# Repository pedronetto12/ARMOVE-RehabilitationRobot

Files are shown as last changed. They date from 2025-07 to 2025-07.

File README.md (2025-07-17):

# ARMOVE - Omnidirectional Robotic Device for Upper Limb Rehabilitation



**Author:** Pedro Netto Gandolfi Grangeiro 
**Advisor:** Prof. Dr. Fabricio Noveletto 
**Institution:** Universidade do Estado de Santa Catarina (UDESC) 
**Course:** Bachelor's in Electrical Engineering 

This repository contains all the necessary files and documentation for the ARMOVE project, an active omnidirectional robotic device for the gross motor function rehabilitation of the upper limb. The project was developed as a Final Coursework (TCC) for the Bachelor's degree in Electrical Engineering at UDESC, Joinville.

---

## 📖 Overview

Motivated by the significant impact of Stroke (CVA) and the high cost of conventional robotic therapies, this project aimed to develop a low-cost, open-source, omnidirectional prototype for the active rehabilitation of the upper limb. 
The device, functionally inspired by the commercial Armotion system, allows a patient to control its movement by applying force to a handle.  It uses a set of Mecanum wheels for omnidirectional mobility and a force-sensing system to interpret the user's intent.  The processed data is then used to move the robot and can be simultaneously transmitted via Bluetooth to a computer, emulating a mouse for interaction with therapeutic games (gamification).

This work delivers a validated, open-source platform, demonstrating the feasibility of more accessible assistive technologies and inviting multidisciplinary collaboration for its evolution into a complete clinical tool.

<div align="center">
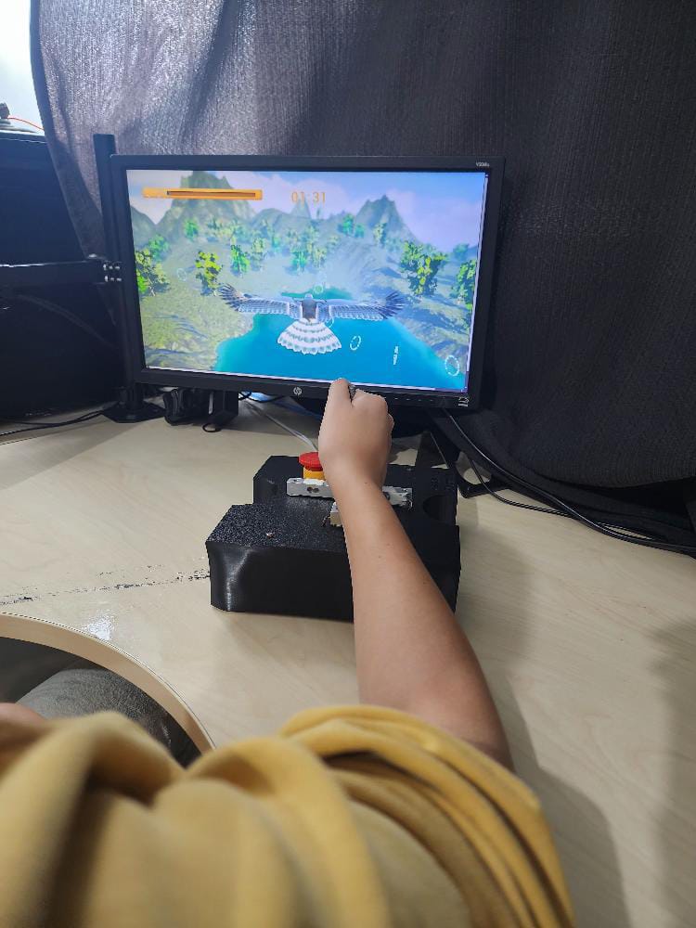
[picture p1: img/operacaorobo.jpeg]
ARMOVE em operação
  
</div>

## ✨ Features

* **Omnidirectional Movement:** Utilizes four Mecanum wheels driven by NEMA 17 stepper motors, allowing for fluid, planar movement in any direction (X-Y plane) without needing to reorient the chassis. 
* **Force-Based Active Control:** The robot operates in an active mode, where the speed and direction of movement are proportional to the force applied by the user on a central joystick. 
* **Smooth Motion Profile:** Implements a non-linear, sigmoidal control law using a hyperbolic tangent (`tanh`) function to ensure smooth acceleration and deceleration, enhancing patient safety and comfort. 
* **Real-Time Processing:** Built on an ESP32 microcontroller running the FreeRTOS real-time operating system, guaranteeing responsive and deterministic control. 
* **Wireless Connectivity:** Features Bluetooth Low Energy (BLE) to connect to external devices, emulating a Human Interface Device (HID) mouse for immediate visual feedback and interaction with rehabilitation software. 
* **Open Source:** All design files, including firmware source code, 3D models for the chassis, and electronic diagrams, are publicly available to encourage collaboration and further development.

## 🛠️ Hardware

The prototype integrates the following key components:

| Component | Model/Type | Function |
| :--- | :--- | :--- |
| **Microcontroller** | ESP32-WROOM-32 | Central processing unit, managing sensors, motors, and BLE communication.  |
| **Actuators** | 4x NEMA 17 Stepper Motors | Provide high-torque, precise movement for the wheels.  |
| **Motor Drivers** | 4x A4988 | Control the current and stepping of the NEMA 17 motors.  |
| **Wheels** | 4x 60mm Mecanum Wheels | Enable omnidirectional movement. |
| **Force Sensors** | 4x Micro Load Cells (CZL635) | Measure the force applied by the user in the X and Y axes. |
| **Sensor Amplifiers** | 4x HX711 ADC Modules | Amplify and convert the analog signal from the load cells to a 24-bit digital value. |
| **Power System** | 5S Li-ion Battery Pack (21V) with BMS | Powers the entire system safely. |
| **Voltage Regulator** | LM2596 DC-DC Buck Converter | Steps down the battery voltage for the microcontroller and logic circuits. |
| **Chassis** | Custom 3D Printed (PLA) | Houses all electronic and mechanical components. |

### Electrical Diagram
The complete electrical schematic detailing the interconnections between all components can be found at the link.
[Electrical Diagram](https://github.com/pedronetto12/ARMOVE-RehabilitationRobot/blob/main/img/Schematic_tccpedronetto_2025-07-16.png)

## 💻 Software

The embedded software is built using the **PlatformIO** framework within VSCode. This ensures a reproducible build environment by managing exact versions of libraries and the ESP32 hardware platform (`espressif32@6.2.0`). 

### Architecture
The architecture is modular and built upon the **FreeRTOS** real-time operating system to handle concurrent tasks efficiently. 
* **Key Modules:**
    * `celulas.h`: Manages data acquisition and processing from the HX711 load cells.
    * `motor.h`: Handles the control logic, kinematics, and pulse generation for the stepper motors.
    * `robomouse.h`: Manages the BLE connection and HID mouse emulation.
* **Real-Time Tasks:**
    1.  **Motor Control (`ContrMotores`):** A high-priority task running every 2 ms to ensure fluid motor updates.
    2.  **Sensor Reading (`atuador`):** A task dedicated to reading and processing data from the load cells.
    3.  **Bluetooth (`ContrMouse`):** A lower-priority task that sends cursor movement data over BLE.
    4.  **LED Status (`ledTask`):** A simple task to provide visual feedback on the system's state.

## ⚙️ Installation & Setup

1.  **Clone the Repository:**
    ```bash
    git clone [https://github.com/pedronetto12/ARMOVE-Rehabilitation-Robot.git](https://github.com/pedronetto12/ARMOVE-Rehabilitation-Robot.git)
    cd ARMOVE-Rehabilitation-Robot
    ```
2.  **Hardware Assembly:** Assemble the mechanical and electronic components according to the electrical diagram and 3D models. The 3D models (`.stl` files) for printing are available in the `/3d_models` directory.
3.  **Software Environment:**
    * Install [Visual Studio Code](https://code.visualstudio.com/).
    * Install the [PlatformIO IDE extension](https://platformio.org/platformio-ide) from the VSCode marketplace.
4.  **Build and Upload:**
    * Open the cloned repository folder in VSCode.
    * PlatformIO will automatically detect the `platformio.ini` file and prompt you to install the required libraries and toolchains.
    * Connect the ESP32 to your computer.
    * Build and upload the firmware using the PlatformIO toolbar (click the "Upload" arrow icon).

## 🎛️ Calibration

Before operation, two critical calibration procedures must be performed to ensure accuracy and safety.

### 1. A4988 Stepper Driver Calibration
This procedure sets the maximum current for the stepper motors to prevent overheating.

1.  **Calculate V_REF:** The target current was set to **1.0A** (80% of the motor's 1.3A rating).  With 0.1Ω sense resistors on the A4988 modules, the target reference voltage (V_REF) is **0.8V (800mV)**. 
2.  **Adjust Potentiometer:**
    * Power the logic and motor circuits. **Do not connect the motors yet.** 
    * Using a multimeter, measure the voltage between the `GND` pin and the metal top of the potentiometer on one of the A4988 drivers.
    * Slowly turn the potentiometer with a small screwdriver until the multimeter reads **0.800V**. 
    * Repeat this process for all four drivers.

### 2. Load Cell (HX711) Calibration
This procedure determines the calibration factor needed to convert the raw ADC readings into grams.

1.  **Load Calibration Sketch:** Use a standard HX711 calibration sketch (like the one found in the `HX711_ADC` library examples).
2.  **Run the Procedure:**
    * Upload and run the sketch on the ESP32 with the load cells connected.
    * Open the Serial Monitor. Follow the on-screen instructions.
    * First, the program will perform a tare (zeroing) with no weight on the platform.
    * Next, place a **known weight** (e.g., 5 kg) on the sensor platform.
    * Enter the known weight value (e.g., `5000.0` for grams) into the serial monitor.
    * The sketch will calculate and display a new calibration factor.
3.  **Update Firmware:** Record the calibration factors for each of the four load cells and update the following `#define` constants in `/include/celulas.h`:
    ```cpp
    #define calValueCellXp 43.53 // Replace with your value
    #define calValueCellXn 41.06 // Replace with your value
    #define calValueCellYp 43.22 // Replace with your value
    #define calValueCellYn 43.50 // Replace with your value
    ```

## ▶️ How to Operate

1.  **Power On:** Turn on the main power switch. The onboard LED will blink during initialization.
2.  **Ready State:** The LED will turn solid, indicating that initialization is complete and the device is ready. The BLE service is now advertising.
3.  **Connect via Bluetooth:** On a computer, search for Bluetooth devices and pair with **"Rehabilitation Robot"**. The device will be recognized as a standard mouse.
4.  **Begin Therapy:**
    * Place the robot on a flat, smooth surface.
    * The user places their hand on the joystick/handle and applies force in the desired direction of movement.
    * The robot will move across the surface, and the computer's cursor will move in sync, allowing interaction with games or other rehabilitation software.

## 🚧 Limitations & Future Work

While the prototype successfully validates the core concept, several limitations were identified that pave the way for future improvements.

### Current Limitations
* **Active Mode Only:** The current design is only suitable for patients who can actively generate force. It does not support passive (robot-led) or active-assistive modes for patients with more severe impairment.
* **Rotational Drift:** The device experiences minor, unintentional rotations around its central axis during movement, which can accumulate over time.
* **Sensor Drift:** The load cells can exhibit drift and hysteresis, especially under traction forces, preventing a perfect return to zero.

### Future Development Roadmap
The evolution of this project depends on a multidisciplinary effort. Key areas for future work include:

1.  **Hardware Enhancements:**
    * **Orientation Control:** Integrate an Inertial Measurement Unit (IMU) (e.g., MPU6050) to implement a closed-loop control system that corrects rotational drift.
    * **Passive/Assistive Modes:** Add encoders to the motors for position feedback, enabling the implementation of passive and active-assistive therapeutic modes.
    * **Sensor Redesign:** Explore bidirectional force sensors or a new mechanical arrangement to eliminate sensor drift.
2.  **Software Development:**
    * **Gamification Suite:** Develop a dedicated suite of therapeutic games that leverage the device's IHM for engaging and measurable rehabilitation exercises.
3.  **Clinical Validation:**
    * Collaborate with physiotherapists and occupational therapists to conduct usability tests and controlled clinical trials to validate the device's therapeutic effectiveness.

## 🤝 How to Contribute

This is an open-source project, and contributions are highly welcome! To contribute:

1.  Fork the repository.
2.  Create a new branch (`git checkout -b feature/YourFeature`).
3.  Commit your changes (`git commit -m 'Add some feature'`).
4.  Push to the branch (`git push origin feature/YourFeature`).
5.  Open a Pull Request.

Please open an issue to discuss any major changes you would like to make.

## 📜 License

This project is licensed under the MIT License. See the [LICENSE](LICENSE.md) file for details.

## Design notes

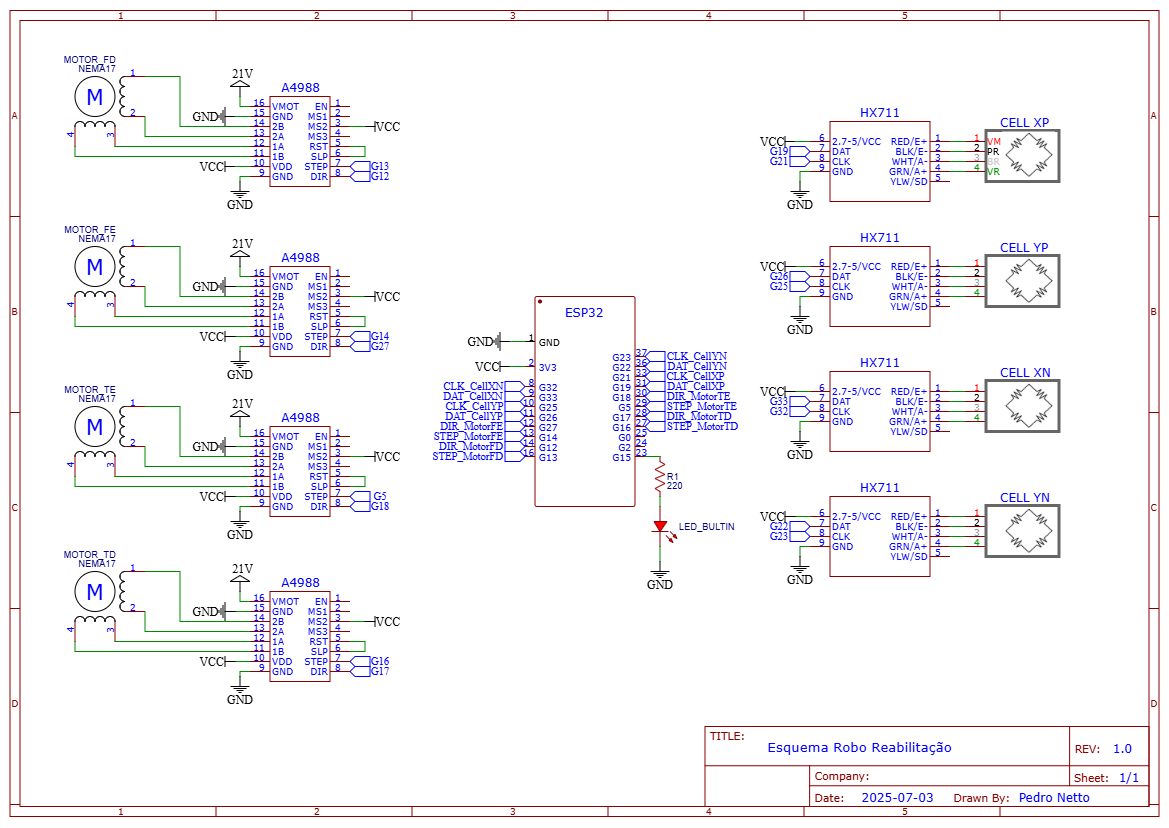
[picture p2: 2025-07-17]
img/Schematic_tccpedronetto_2025-07-16.png

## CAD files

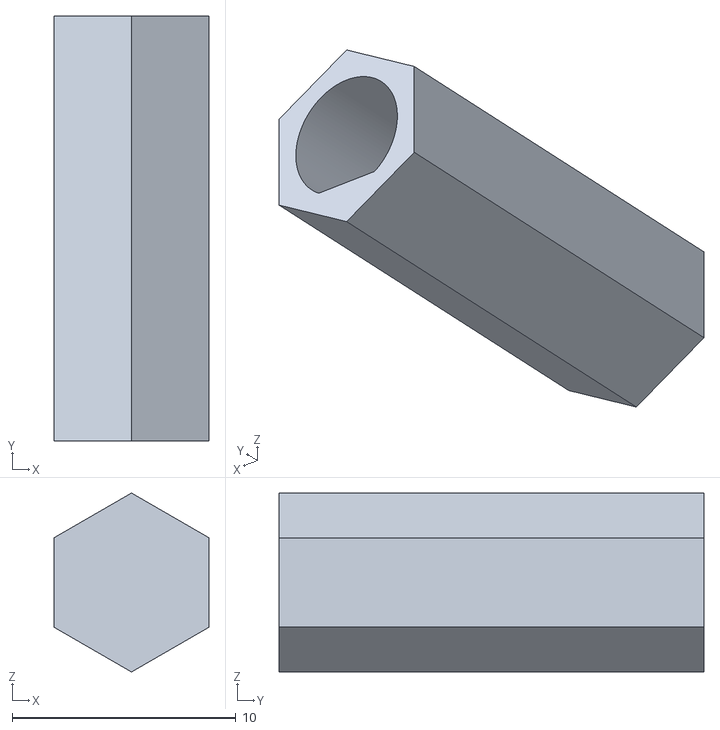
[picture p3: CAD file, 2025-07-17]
SLT_FILES/luva direta.stl
6.93 x 19.0 x 8.00

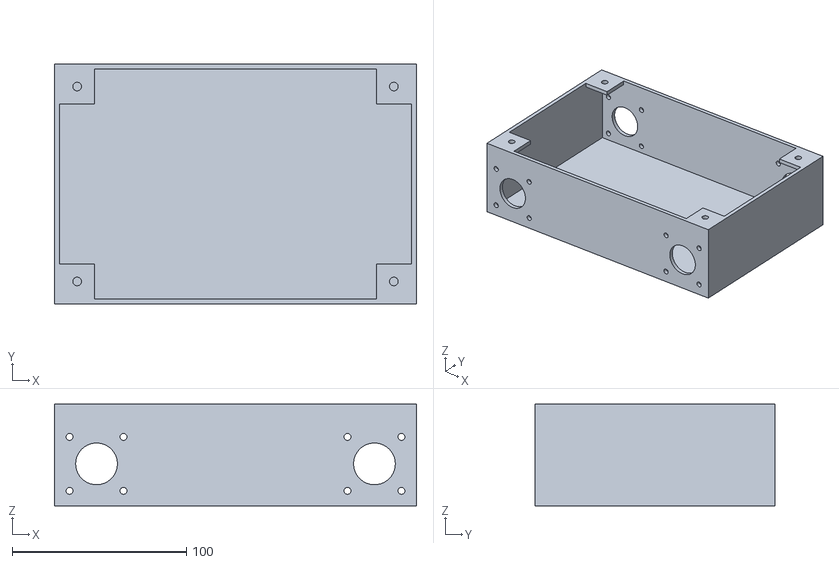
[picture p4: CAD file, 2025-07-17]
SLT_FILES/base case tcc pedro.stl
208.0 x 138.0 x 58.5

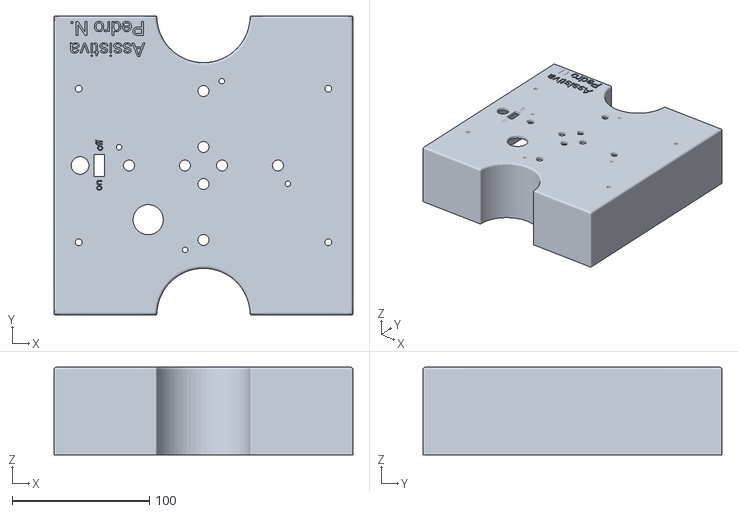
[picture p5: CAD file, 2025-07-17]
SLT_FILES/topo tcc pedro222.stl
218.0 x 218.0 x 64.0

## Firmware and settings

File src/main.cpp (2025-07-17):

#include <main.h>

void setup() {
  WRITE_PERI_REG(RTC_CNTL_BROWN_OUT_REG, 0);// desliga o brownout detector, se nao o modulo fica resetando
  Serial.begin(115200);

  xTaskCreatePinnedToCore(ledTask, "LED", 1024, NULL, 1, NULL, 1);
  CellInit(); //inicializa e configura a leitura das celulas de carga
  MotorInit(); //inicializa as configs dos motores
  MouseInit(); //inicializa as configs do Mouse

  xTaskCreatePinnedToCore(atuador,"celula_carga",1024 * 2, NULL, 1, NULL, 1);
  xTaskCreatePinnedToCore(ContrMotores,"Ctrlmotores",1024 * 2, NULL, 2, NULL, 1);
  xTaskCreatePinnedToCore(ContrMouse,"Contrmouse",1024 * 2, NULL, 3, NULL, 1);
  Inicializado = true;
}

void loop() {}

void ContrMotores (void *parameters){
  const TickType_t xDelay = pdMS_TO_TICKS(1);  // 2ms -> ticks
  while(1){
    motorRun();
    vTaskDelay(xDelay);  // Espera 2ms antes de rodar de novo
  }
}

void atuador (void *parameters){
  const TickType_t yDelay = pdMS_TO_TICKS(1);  // 2ms -> ticks
  while(1){
    leituraCelulas();
    vTaskDelay(yDelay);  // Espera 2ms antes de rodar de novo
  }
}

void ContrMouse (void *parameters){
  const TickType_t zDelay = pdMS_TO_TICKS(20);  // 20ms -> ticks
  while(1){
    MoveCursor(getLoadCellValues());
    vTaskDelay(zDelay);  // Espera 20ms antes de rodar de novo
  }
}


void ledTask(void *parameters) {
  const TickType_t delayTime = pdMS_TO_TICKS(300); // 300ms
  pinMode(LED_BUILTIN, OUTPUT);
  while (1) {
    if(Inicializado){
      digitalWrite(LED_BUILTIN, HIGH);
    }else{
      digitalWrite(LED_BUILTIN, HIGH);
      vTaskDelay(delayTime);
      digitalWrite(LED_BUILTIN, LOW);
      vTaskDelay(delayTime);
    }
  }
}

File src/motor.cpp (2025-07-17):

#include <motor.h>

  esp_timer_handle_t periodic_timer;
  //motores
  MOTOR Motor_FE={0,0,0,0,0};
  MOTOR Motor_TE={0,0,0,0,0};
  MOTOR Motor_FD={0,0,0,0,0};
  MOTOR Motor_TD={0,0,0,0,0};

void MotorInit(){
  Serial.println("Inicio do Init Motores");
  //timer interrupção
  const esp_timer_create_args_t periodic_timer_args = {
    .callback = &onTimer,
    .arg = nullptr,
    .dispatch_method = ESP_TIMER_TASK,
    .name = "motor_step_timer"
  };

  esp_timer_create(&periodic_timer_args, &periodic_timer);
  esp_timer_start_periodic(periodic_timer, 50); // 50us

  pinMode(motorFE_STEP_PIN, OUTPUT);
  pinMode(motorFE_DIR_PIN, OUTPUT);

  pinMode(motorTE_STEP_PIN, OUTPUT);
  pinMode(motorTE_DIR_PIN, OUTPUT);

  pinMode(motorFD_STEP_PIN, OUTPUT);
  pinMode(motorFD_DIR_PIN, OUTPUT);

  pinMode(motorTD_STEP_PIN, OUTPUT);
  pinMode(motorTD_DIR_PIN, OUTPUT);

  delay(200);
  Serial.println("Fim do Init Motores");
}

void moveByLoadCells(LoadCellData CellData) {
  // Ajuste das velocidades com interpolação linear
  int speedForward = linearInterpolate(CellData.forward, CellDeadZone, CellMax, minWheelSpeed, maxWheelSpeed);
  int speedSideways = linearInterpolate(CellData.sideways, CellDeadZone, CellMax, minWheelSpeed, maxWheelSpeed);
   
  // Cálculo da decomposição de velocidade dos motores
  Motor_FE.Interpolacao = speedForward + speedSideways;  
  Motor_TE.Interpolacao = speedForward - speedSideways;
  Motor_FD.Interpolacao = speedForward - speedSideways;
  Motor_TD.Interpolacao = speedForward + speedSideways;

  // Normalização para evitar saturação
  int maxSpeed = max(abs(Motor_FE.Interpolacao), max(abs(Motor_TE.Interpolacao), max(abs(Motor_FD.Interpolacao), abs(Motor_TD.Interpolacao))));
  if (maxSpeed > maxWheelSpeed) {
    float scale = (float)maxWheelSpeed / maxSpeed;
    Motor_FE.Interpolacao *= scale;
    Motor_TE.Interpolacao *= scale;
    Motor_FD.Interpolacao *= scale;
    Motor_TD.Interpolacao *= scale;
 }
}


void SuavizacaoVelocidade(){
  // Calculo do Pulso do motor frente esquerda
  if(Motor_FE.Interpolacao > 0) Motor_FE.Velocidade = (minVel-maxVel)* tanh(k * pow(abs(Motor_FE.Interpolacao), pot));
  else  Motor_FE.Velocidade = -(minVel-maxVel)* tanh(k * pow(abs(Motor_FE.Interpolacao), pot));

  if(Motor_FE.Interpolacao > 0) Motor_FE.Velocidade = minVel - Motor_FE.Interpolacao;
  else if(Motor_FE.Interpolacao < 0) Motor_FE.Velocidade = -minVel - Motor_FE.Interpolacao;
  else Motor_FE.Velocidade = 0;

  // Calculo do Pulso do motor traseira esquerda
  if(Motor_TE.Interpolacao > 0) Motor_TE.Velocidade = (minVel-maxVel)* tanh(k * pow(abs(Motor_TE.Interpolacao), pot));
  else  Motor_TE.Velocidade = -(minVel-maxVel)* tanh(k * pow(abs(Motor_TE.Interpolacao), pot));

  if(Motor_TE.Interpolacao > 0) Motor_TE.Velocidade = minVel - Motor_TE.Interpolacao;
  else if(Motor_TE.Interpolacao < 0) Motor_TE.Velocidade = -minVel - Motor_TE.Interpolacao;
  else Motor_TE.Velocidade = 0;

  // Calculo do Pulso do motor frente direita
  if(Motor_FD.Interpolacao > 0) Motor_FD.Velocidade = (minVel-maxVel)* tanh(k * pow(abs(Motor_FD.Interpolacao), pot));
  else  Motor_FD.Velocidade = -(minVel-maxVel)* tanh(k * pow(abs(Motor_FD.Interpolacao), pot));

  if(Motor_FD.Interpolacao > 0) Motor_FD.Velocidade = minVel - Motor_FD.Interpolacao;
  else if(Motor_FD.Interpolacao < 0) Motor_FD.Velocidade = -minVel - Motor_FD.Interpolacao;
  else Motor_FD.Velocidade = 0;

  // Calculo do Pulso do motor traseira direita
  if(Motor_TD.Interpolacao > 0) Motor_TD.Velocidade = (minVel-maxVel)* tanh(k * pow(abs(Motor_TD.Interpolacao), pot));
  else  Motor_TD.Velocidade = -(minVel-maxVel)* tanh(k * pow(abs(Motor_TD.Interpolacao), pot));

  if(Motor_TD.Interpolacao > 0) Motor_TD.Velocidade = minVel - Motor_TD.Interpolacao;
  else if(Motor_TD.Interpolacao < 0) Motor_TD.Velocidade = -minVel - Motor_TD.Interpolacao;
  else Motor_TD.Velocidade = 0;

  Motor_FE.pulseOUTPUT = Motor_FE.Velocidade;
  Motor_TE.pulseOUTPUT = Motor_TE.Velocidade;
  Motor_FD.pulseOUTPUT = -Motor_FD.Velocidade; //negativo pois foram colocados do lado espelhado do esquerdo
  Motor_TD.pulseOUTPUT = -Motor_TD.Velocidade; //negativo pois foram colocados do lado espelhado do esquerdo

  /*
  Motor_FE.pulseOUTPUT = 120;
  Motor_TE.pulseOUTPUT = 120;
  Motor_FD.pulseOUTPUT = -120;
  Motor_TD.pulseOUTPUT = -120;
  */
}

void motorRun(){
  moveByLoadCells(getLoadCellValues());
  SuavizacaoVelocidade();
  //printdebug(getLoadCellValues());
}


void printdebug(LoadCellData CellData){
  Serial.print(Motor_FE.Interpolacao);
  Serial.print(",,");
  Serial.print(CellData.pesoYp);
  Serial.print("    ");

  Serial.print(Motor_TE.Interpolacao);
  Serial.print(",,");
  Serial.print(CellData.pesoYn);
  Serial.print("    ");

  Serial.print(Motor_FD.Interpolacao);
  Serial.print(",,");
  Serial.print(CellData.pesoXp);
  Serial.print("    ");

  Serial.print(Motor_TD.Interpolacao);
  Serial.print(",,");
  Serial.println(CellData.pesoXn);
}
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

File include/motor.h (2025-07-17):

#ifndef _MOTOR_H_
#define _MOTOR_H_

#include <celulas.h>
#include <robomouse.h>
#include "esp_timer.h"

//pinos motores
#define motorFE_STEP_PIN 14
#define motorFE_DIR_PIN 27

#define motorTE_STEP_PIN 5
#define motorTE_DIR_PIN 18

#define motorFD_STEP_PIN 13
#define motorFD_DIR_PIN 12

#define motorTD_STEP_PIN 16
#define motorTD_DIR_PIN 17


#define minVel 450
#define maxVel 150
#define pot 0.55
#define k 0.11



struct MOTOR {
    int Interpolacao;
    int Velocidade;
    int pulseOUTPUT;
    int cont;
    int contSTEP_memory;
};


//funções
void MotorInit();
void moveByLoadCells(LoadCellData CellData);
void SuavizacaoVelocidade();
void motorRun();
void printdebug(LoadCellData CellData);
void onTimer(void* arg); //interrupção

#endif

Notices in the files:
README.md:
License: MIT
